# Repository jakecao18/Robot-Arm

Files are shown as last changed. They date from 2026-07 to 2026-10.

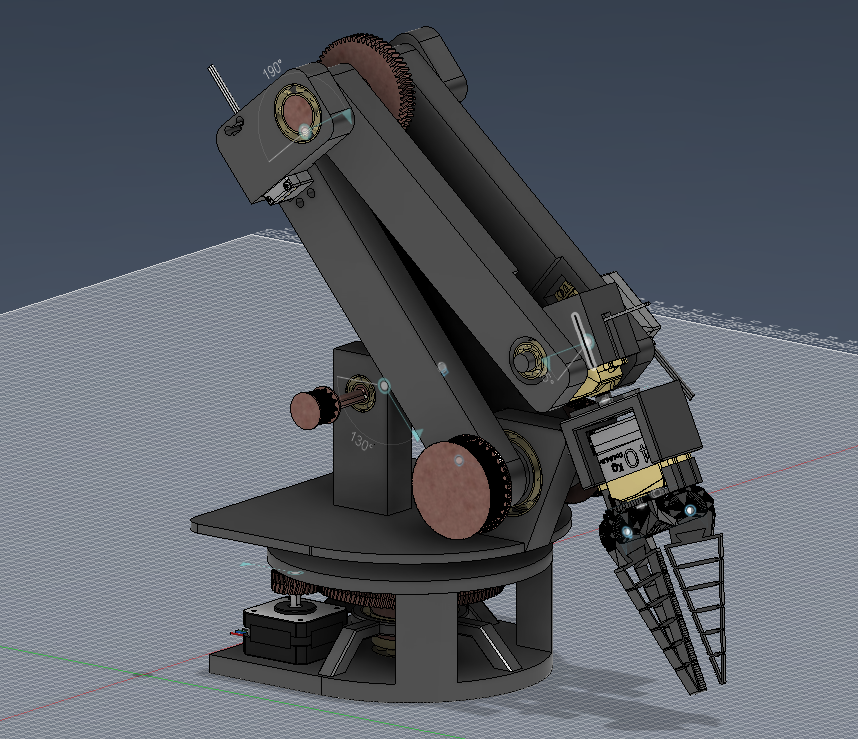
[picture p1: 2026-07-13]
Documents/pictures & videos/picture 5.png

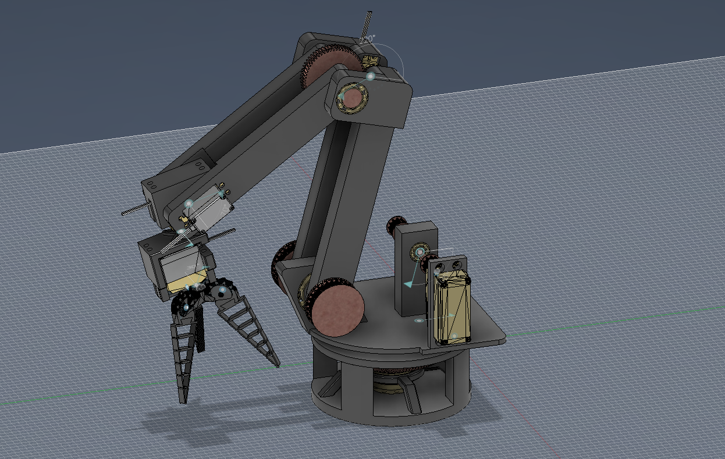
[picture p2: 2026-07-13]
Documents/pictures & videos/picture 1.png

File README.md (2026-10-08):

# 5-DOF Robotic Arm

A 5-DOF desktop robotic arm built for computer vision experiments and automated pick-and-place tasks.

The arm uses 3D-printed parts, high-torque hobby servos, and an ESP32 for control. Servo control is handled through a PCA9685 over I2C.

Part of the **Stardance** project.

## Hardware

| Component | Spec / Model | Qty | Notes |
| --- | --- | --: | --- |
| Microcontroller  | ESP32 DevKit V1 | 1 | Main controller |
| PWM Driver | PCA9685 16-Channel | 1 | I2C servo control |
| Base Servo | 150 kg·cm digital servo | 1 | Base rotation |
| Shoulder / Elbow | 40 kg·cm digital servos | 2 | Main arm joints |
| Wrist / Gripper  | 20 kg·cm digital servos | 2 | Wrist and gripper |
| Power Supply | 12V SMPS | 1 | Stepped down for the servo rail |

The full parts list, prices, and sourcing information are in [`Documents/BOM.csv`](Documents/BOM.csv).

## Project Status

* [x] Full CAD assembly in Fusion 360
* [x] Wiring schematic and power distribution
* [x] Bill of Materials
* [x] Structural parts 3D printed
* [x] Mechanical assembly and dry-fit
* [x] Servo calibration and zero-point alignment
* [x] Forward and inverse kinematics
* [x] ESP32 firmware and PCA9685 control
* [ ] OpenCV camera integration
* [ ] Object detection
* [ ] Autonomous pick-and-place

## Repository

```text
├── CAD/
│   ├── Assembly/              # Complete Fusion 360 models
│   └── Individual Parts/      # Printable STL/STEP files
│
├── Code/                      # ESP32 firmware and control scripts
│
├── Documents/
│   ├── BOM.csv                # Parts, pricing, and specifications
│   ├── Pictures/              # Build photos and progress
│   └── Wiring_Schematic.*     # System schematics
│
└── README.md
```

## Software

* **CAD:** Autodesk Fusion 360
* **Firmware:** C++ / Arduino IDE
* **Microcontroller:** ESP32
* **Servo Control:** PCA9685 over I2C
* **Kinematics:** Python, NumPy
* **Computer Vision:** OpenCV
* **Development:** VS Code

## License

MIT License

Designed and built by Jake.

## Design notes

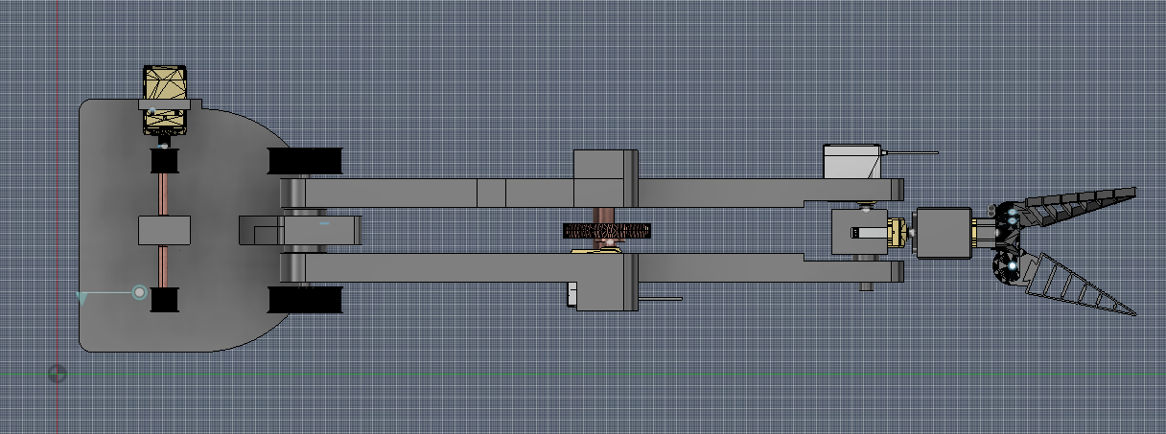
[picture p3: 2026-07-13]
Documents/pictures & videos/picture 4.png

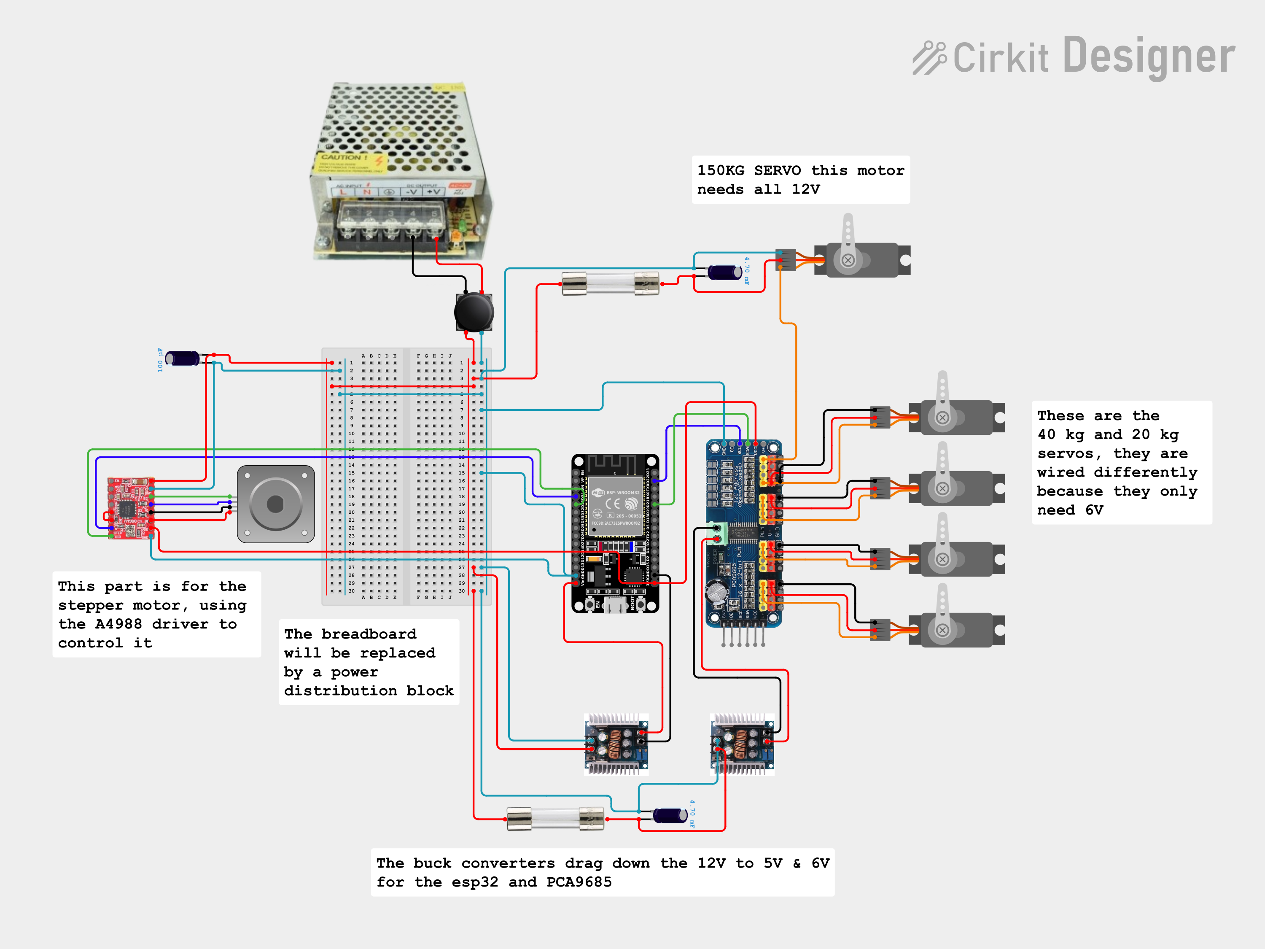
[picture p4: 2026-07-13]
Documents/pictures & videos/circuit_image.png

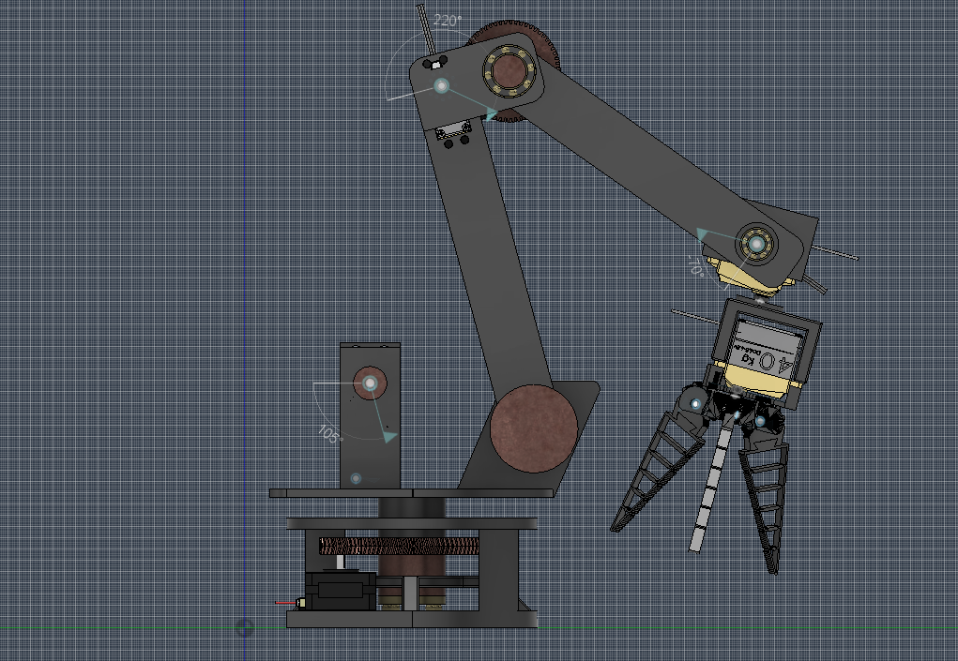
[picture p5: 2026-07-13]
Documents/pictures & videos/picture 2.png

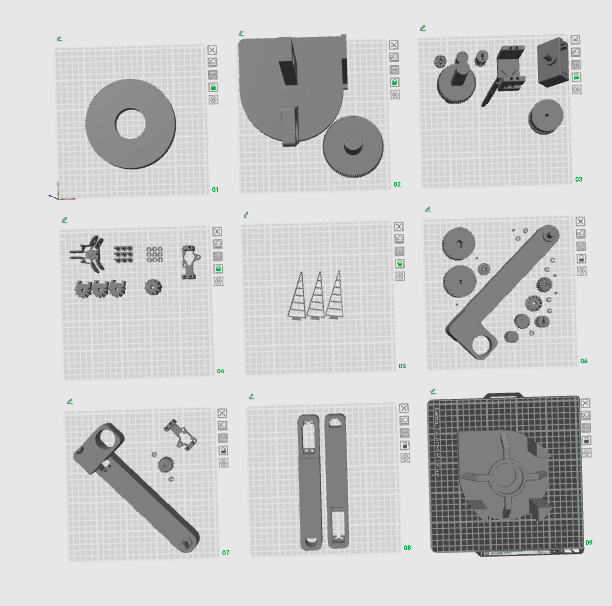
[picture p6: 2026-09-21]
Documents/pictures & videos/Screenshot 2026-07-12 210158.png

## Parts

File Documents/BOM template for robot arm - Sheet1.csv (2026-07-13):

Item Name | Qty | Price (total) (CAD) | Item link | Notes
nema 17 stepper | 1 | $15.99 | link | This is an example part! Add things to note here.
20kg servo | 2 | $35.99 | link | Servo for wrist roll and gripper
40kg servo | 2 | $45.59 | link | Servo for elbow and wrist
150kg servo | 1 | $46.99 | link | Servo for shoulder
esp32 | 1 | $8.06 | link | Microcontroller to control all motors
thrust ball bearing 20mm x 40mm x 14mm | 1 | $11.26 | link | Ball bearing at the base
ball bearing 10mm x 26mm x 8mm | 3 | $13.75 | link | Ball bearing at the shoulder and wrist
ball bearing 35mm x 47mm x 7mm | 2 | $12.89 | link | Ball bearing at the base
ball bearing 20mm x 32mm x 7mm | 2 | $11.09 | link | Ball bearing at the shoulder
HTD5M-325mm 15mm width pulley timing belt | 2 | $19.19 | link | Belt to connect belt gears on the shoulder
PCA9685 | 1 | $13.56 | link | Servo motor driver that handles outputting all the PWM signals
adjustable buck converter 12V - 5 & 6V | 2 | $19.99 | link | Buck convertor to lower voltage from 12V down to 5V for esp32 and 6V for PCA9685
capacitor 4700 uf | 2 | $11.32 | link | Capacitors will be used to prevent voltage spikes; this is for the servos. This is actually 5 pieces, although you just need 2
SMPS 12V 20A | 1 | $27.89 | link | Power cord not included, so you would need one. Cutting up an old computer power cord can also work
fuse | 2 | $11.69 | link | This is a 4-pack, but you only need 2. The fuses prevent short-circuit damage
power distribution block | 1 | $18.51 | link | Power distribution block lets everything be more organized, it's optional since wires can be plugged directly into the power supply
12 AWG wire | 3ft | $11.39 | link | Thicker wires can safely handle the 12V 20A power without any fluctuation or trouble, you would also need regular jumper wires
A4988 stepper motor driver | 1 | $3.50 | link | This part controls the stepper motor
capacitor 100 uf | 1 | $2.17 | link | This capacitor will be used for the stepper motor. This is 10 pieces but you only need 1
Total Price (USD): | $340.82
All of these parts are just the ones I found immediately on Amazon; you can probably find the exact same parts for cheaper on Amazon or even somewhere else.

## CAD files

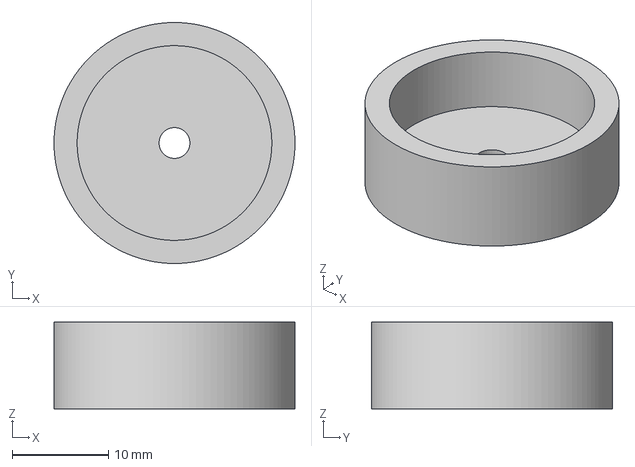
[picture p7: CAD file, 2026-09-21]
CAD files/CAD parts obj/elbow big gear cap.3mf
25.0 x 25.0 x 9.00 mm

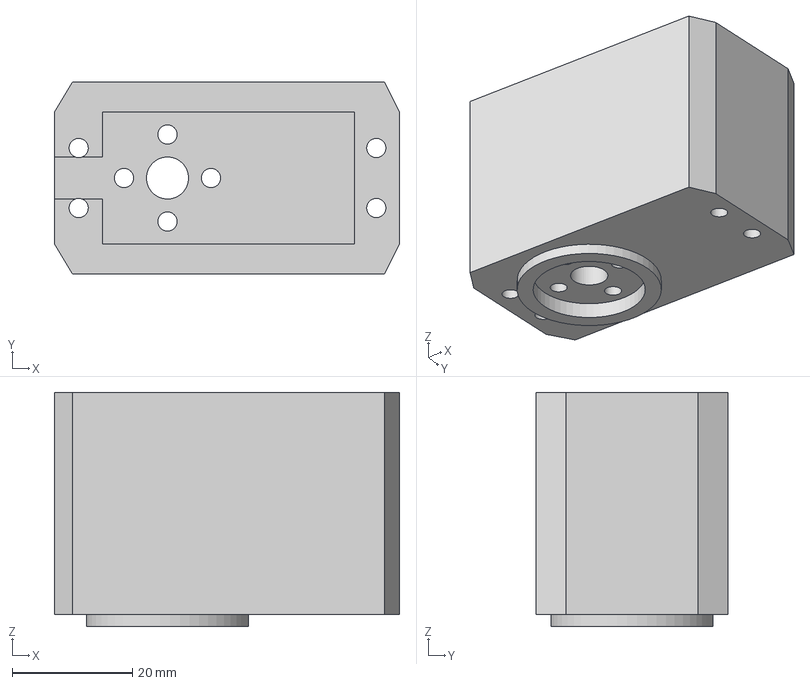
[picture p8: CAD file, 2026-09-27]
CAD files/CAD parts step/gripper holder.step
57.5 x 32.0 x 39.0 mm

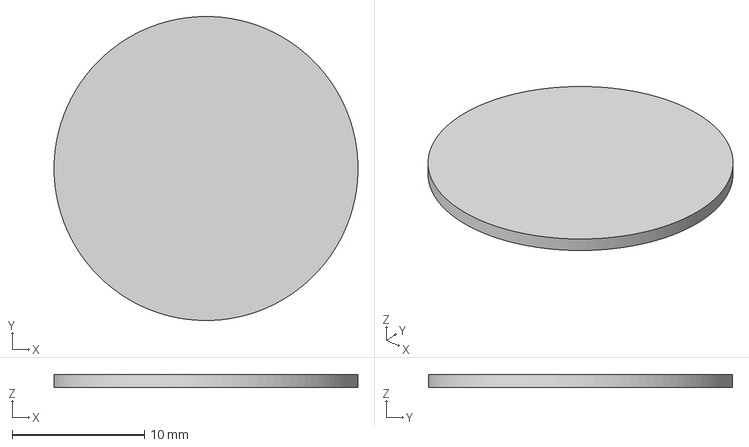
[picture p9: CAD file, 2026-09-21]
CAD files/CAD parts obj/elbow bb cover.3mf
23.0 x 23.0 x 1.00 mm

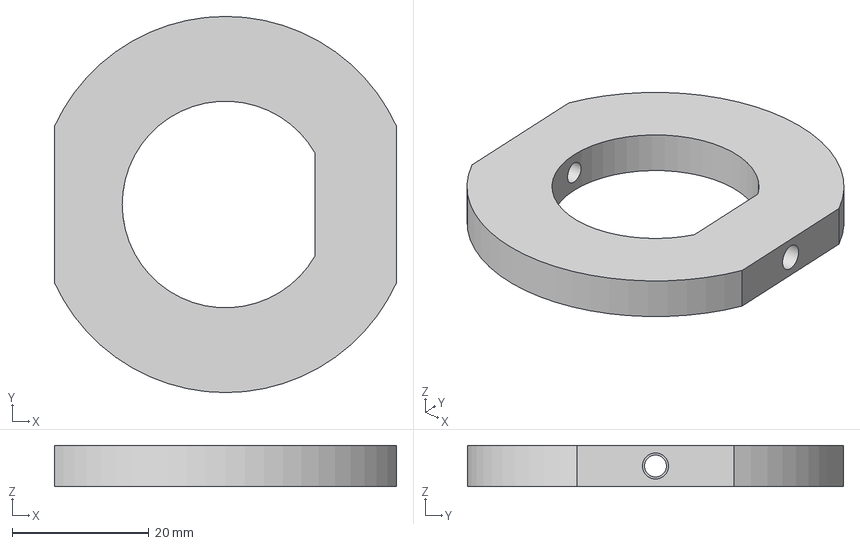
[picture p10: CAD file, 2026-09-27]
CAD files/CAD parts step/shoulder shaft connect support.step
50.0 x 55.0 x 6.00 mm

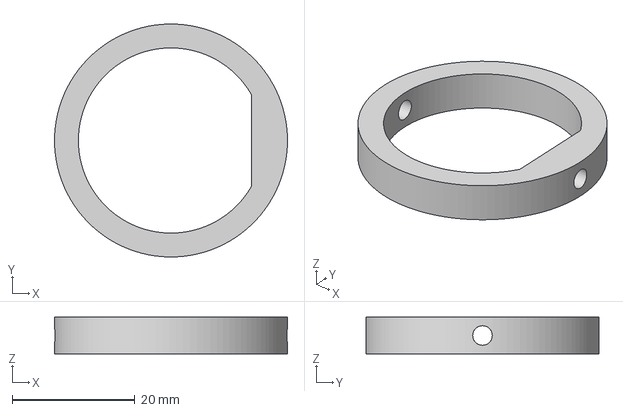
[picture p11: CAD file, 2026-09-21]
CAD files/CAD parts obj/shoulder shaft bearing holder.3mf
38.0 x 38.0 x 6.00 mm

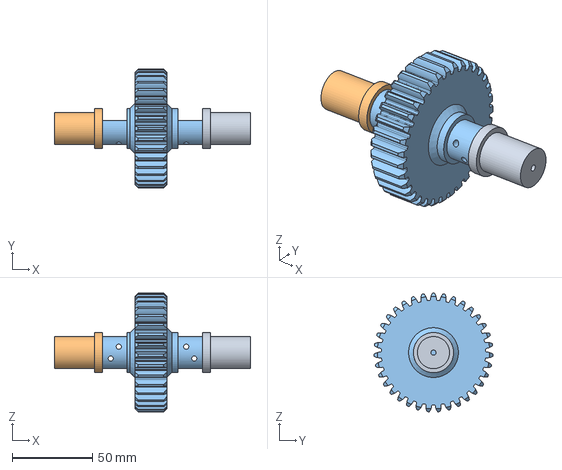
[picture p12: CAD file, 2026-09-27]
CAD files/CAD parts step/elbow big gear .step
122.0 x 74.0 x 73.9 mm

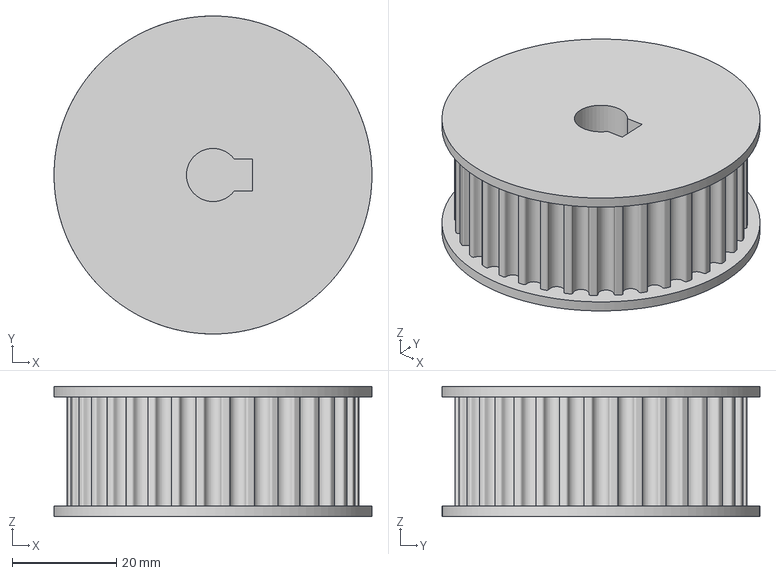
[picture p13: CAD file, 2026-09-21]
CAD files/CAD parts obj/shoulder big belt gear.3mf
61.0 x 61.0 x 25.0 mm

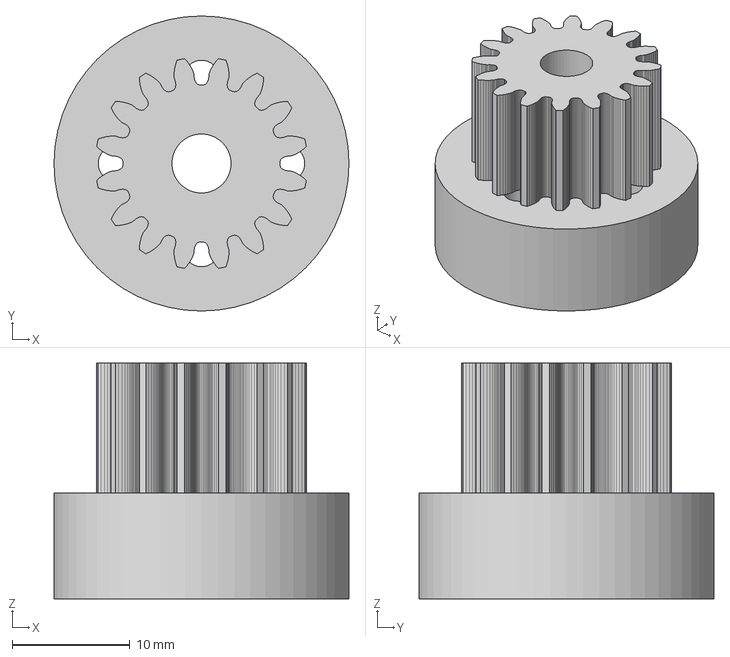
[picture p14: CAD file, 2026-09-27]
CAD files/CAD parts step/gripper pinion.step
25.0 x 25.0 x 20.0 mm

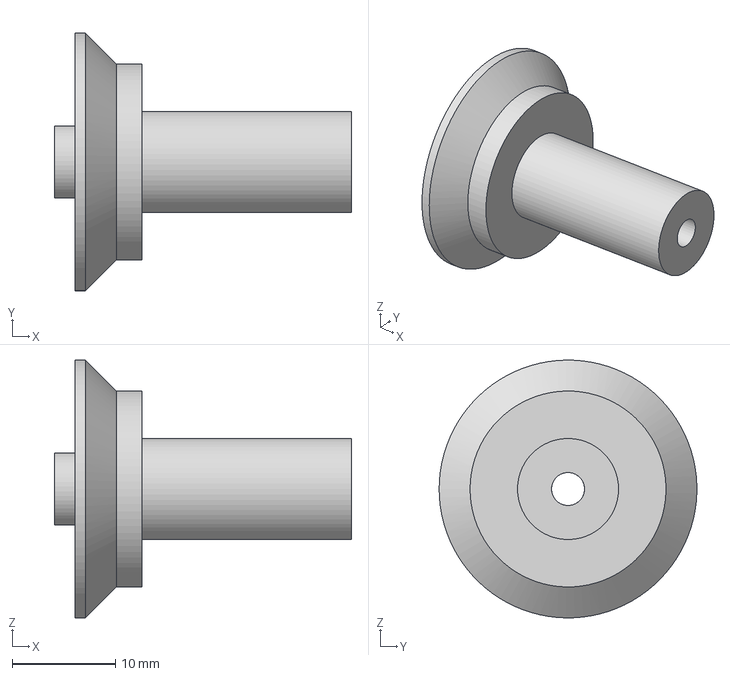
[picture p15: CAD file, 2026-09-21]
CAD files/CAD parts obj/wrist holder2.3mf
28.8 x 25.0 x 25.0 mm

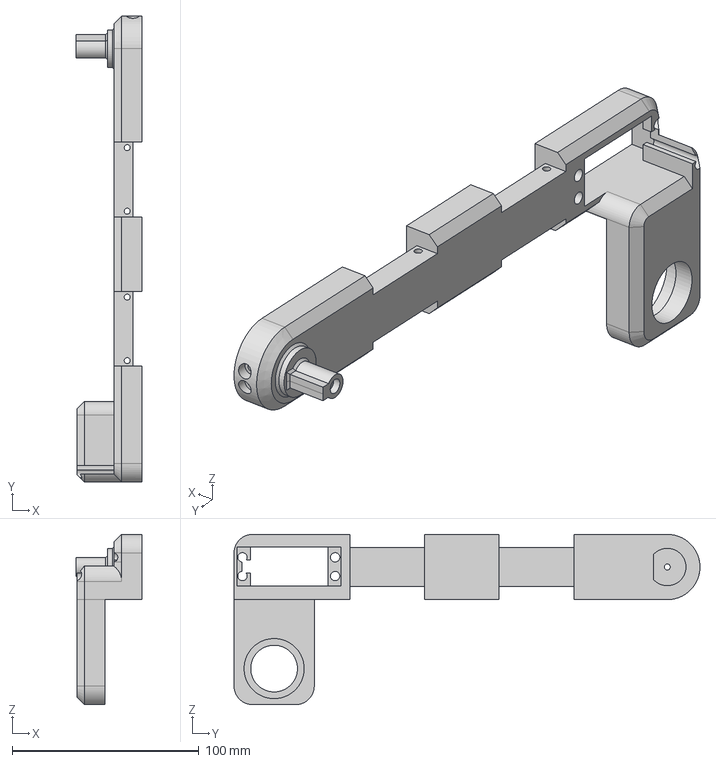
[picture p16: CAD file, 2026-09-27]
CAD files/CAD parts step/shoulder shaft right.step
35.5 x 249.5 x 91.2 mm

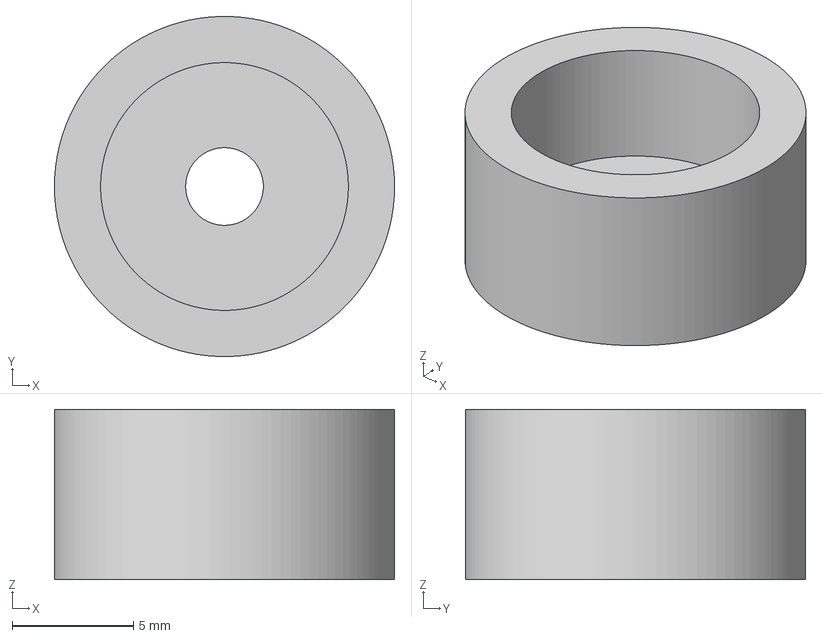
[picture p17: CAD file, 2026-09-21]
CAD files/CAD parts obj/elbow small gear cap.3mf
14.0 x 14.0 x 7.00 mm

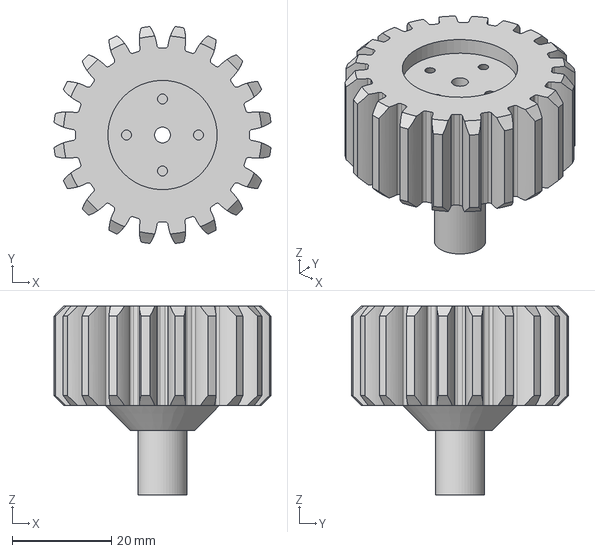
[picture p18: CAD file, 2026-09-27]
CAD files/CAD parts step/elbow small gear .step
43.7 x 43.7 x 38.0 mm

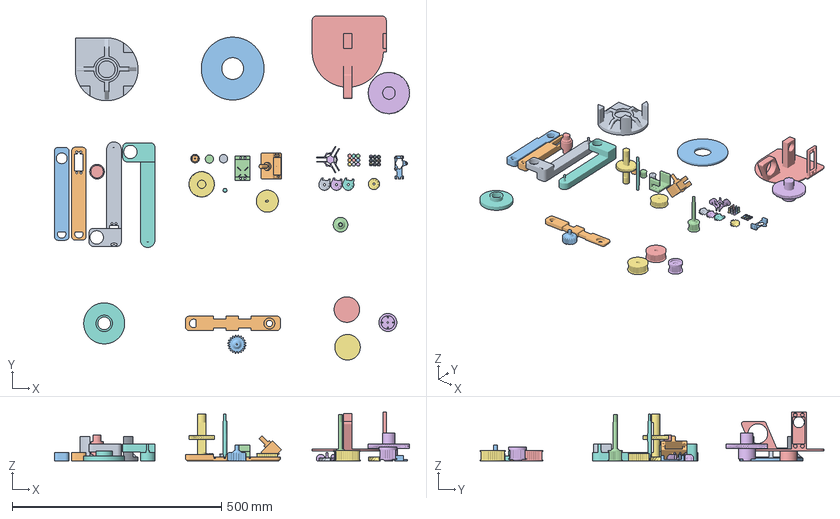
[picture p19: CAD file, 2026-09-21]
CAD files/CAD parts obj/base big gear.3mf
848.3 x 821.3 x 116.9 mm
base plate (1)
servo connect (1) (1)
top base plate
belt gear1 (1) x 2
shoulder plate (2) (2)
herringbone-97.obj
herringbone-59 (1)
arm shaft right (1) (1) (2)
arm shaft left (1) (1) (1) (1)
arm shaft left (3) (1) (2)
arm connect (1)
Gear_Holder
htd-pitch5mm-width15mm-32tooth
MeshBody7
base
Bolt_Clip x 9
Bolt x 9
Gear_1 (2) x 3
servo gear
MeshBody1 x 3
MeshBody1 (1) (1)

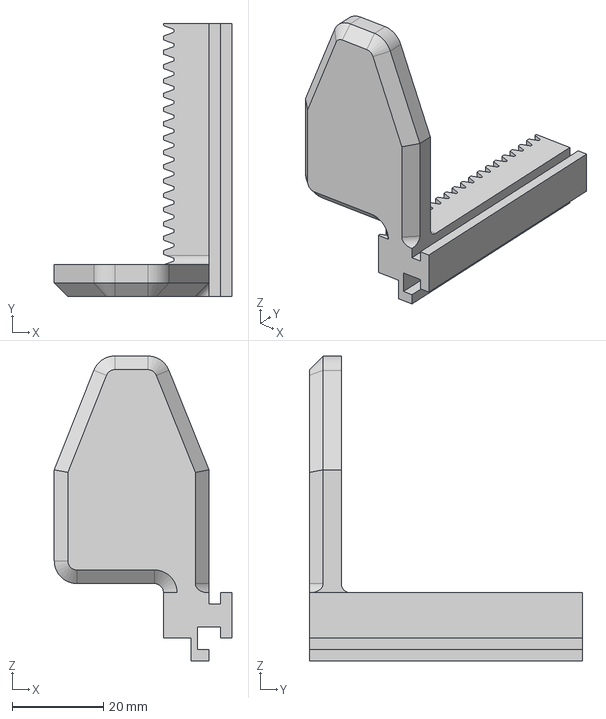
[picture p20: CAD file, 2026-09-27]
CAD files/CAD parts step/gripper rack.step
39.0 x 60.0 x 67.0 mm

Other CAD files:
CAD files/CAD parts obj/elbow big gear arms.3mf
CAD files/CAD parts step/shoulder shaft support.step
CAD files/CAD parts obj/gripper servo gear.3mf
CAD files/CAD parts step/top base plate.step
CAD files/CAD parts obj/base plate (1).3mf
CAD files/CAD parts obj/base small gear.3mf
CAD files/CAD parts obj/elbow big gear.3mf
CAD files/CAD parts obj/elbow shaft left.3mf
CAD files/CAD parts obj/elbow shaft right.3mf
CAD files/CAD parts obj/elbow shaft support.3mf
CAD files/CAD parts obj/elbow small gear.3mf
CAD files/CAD parts obj/gripper base.3mf
CAD files/CAD parts obj/gripper bolt clip.3mf
CAD files/CAD parts obj/gripper bolt.3mf
CAD files/CAD parts obj/gripper finger gear.3mf
CAD files/CAD parts obj/gripper finger.3mf
CAD files/CAD parts obj/gripper gear holder.3mf
CAD files/CAD parts obj/gripper holder.3mf
CAD files/CAD parts obj/servo attach plug.3mf
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

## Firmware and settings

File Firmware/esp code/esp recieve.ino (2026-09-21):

#include <Wire.h>
#include <Adafruit_PWMServoDriver.h>
#include <WiFiUdp.h>
#include <ArduinoJson.h>
#include <WiFi.h>

#define STEP_PIN 2
#define DIR_PIN 4
#define EN_PIN 23

long currentSteps = 0;
long targetSteps = 0;
long elbowCurrent = 90;
long wristPitchCurrent = 90;
long shoulderCurrent = 90;

unsigned long lastStepTime = 0;
const unsigned long stepInterval = 7000;  // microseconds

const char* ssid = "westlake2022";
const char* password = "workIsFUN2023";

WiFiUDP udp;

const int UDP_PORT = 5000;

Adafruit_PWMServoDriver pwm = Adafruit_PWMServoDriver();

//array of max and min of servos 0 - 4
//calibrated servos 0, 1, & 2 
int servoMax[] = {2930, 3000, 3000, 2750, 2750};
int servoMin[] = {480, 450, 450, 500, 500};

//function that converts angle into pwm pulse
void writeAngle(int servoNum, double angle){
  //servo-0 has a range of 270 degrees therefor needing seperate mapping
  if(servoNum == 0){
    angle = constrain(angle, 0, 270);
    double pwmSignal = map(angle, 0, 270, servoMin[servoNum], servoMax[servoNum]);
    pwm.writeMicroseconds(servoNum, pwmSignal);
  }
  else if(servoNum == 1 || servoNum == 2){
    angle = constrain(angle, 0, 298);
    double pwmSignal = map(angle, 0, 298, servoMin[servoNum], servoMax[servoNum]);
    pwm.writeMicroseconds(servoNum, pwmSignal);
  }
  else{
    angle = constrain(angle, 0, 270);
    double pwmSignal = map(angle, 0, 270, servoMin[servoNum], servoMax[servoNum]);
    pwm.writeMicroseconds(servoNum, pwmSignal);
    Serial.print(pwmSignal);
  }
}

void setStepperAngle(float angle) {
  // Convert angle to absolute step position
  targetSteps = round(angle / 1.8);
}

void runStepper() {
  // Already at target
  if (currentSteps == targetSteps) {
    return;
  }
  // Don't step too quickly
  if (micros() - lastStepTime < stepInterval) {
    return;
  }

  lastStepTime = micros();

  // Need to move forward
  if (targetSteps > currentSteps) {
    digitalWrite(DIR_PIN, HIGH);

    digitalWrite(STEP_PIN, HIGH);
    delayMicroseconds(2);
    digitalWrite(STEP_PIN, LOW);

    currentSteps++;
  }

  // Need to move backward
  else {
    digitalWrite(DIR_PIN, LOW);

    digitalWrite(STEP_PIN, HIGH);
    delayMicroseconds(2);
    digitalWrite(STEP_PIN, LOW);

    currentSteps--;
  }
}

void setup() {
  //initialize pwm
  pwm.begin();
  pwm.setPWMFreq(50);

  pinMode(23, OUTPUT);
  digitalWrite(23, LOW);

  WiFi.begin(ssid, password);
  Serial.begin(115200);

  while (WiFi.status() != WL_CONNECTED) {
      delay(500);
      Serial.print(".");
  }

  Serial.println();
  Serial.println("WiFi connected!");

  Serial.print("ESP32 IP address: ");
  Serial.println(WiFi.localIP());

  udp.begin(UDP_PORT);

  Serial.print("Listening on UDP port: ");
  Serial.println(UDP_PORT);

  pinMode(STEP_PIN, OUTPUT);
  pinMode(DIR_PIN, OUTPUT);
  pinMode(EN_PIN, OUTPUT);

  // Enable A4988
  digitalWrite(EN_PIN, LOW);
  digitalWrite(DIR_PIN, HIGH);

}

void moveShoulderSlow(int targetShoulder) {

  while (shoulderCurrent != targetShoulder) {

    if (shoulderCurrent < targetShoulder)
      shoulderCurrent++;
    else if (shoulderCurrent > targetShoulder)
      shoulderCurrent--;

    writeAngle(0, shoulderCurrent);

    delay(15);
  }
}


void moveElbowSlow(int targetElbow) {

  while (elbowCurrent != targetElbow) {

    if (elbowCurrent < targetElbow)
      elbowCurrent++;
    else if (elbowCurrent > targetElbow)
      elbowCurrent--;

    writeAngle(1, elbowCurrent);

    delay(15);
  }
}


void moveWristPitchSlow(int targetWristPitch) {

  while (wristPitchCurrent != targetWristPitch) {

    if (wristPitchCurrent < targetWristPitch)
      wristPitchCurrent++;
    else if (wristPitchCurrent > targetWristPitch)
      wristPitchCurrent--;

    writeAngle(2, wristPitchCurrent);

    delay(15);
  }
}

void loop() {

  int packetSize = udp.parsePacket();

  if (packetSize > 0) {

    char packet[256];

    int length = udp.read(packet, 255);
    packet[length] = '\0';

    Serial.print("Received: ");
    Serial.println(packet);

    JsonDocument data;

    DeserializationError error = deserializeJson(data, packet);

    if (error) {
      Serial.println("JSON error");
      return;
    }

    float base = data["base"];
    float shoulder = data["shoulder"];
    float elbow = data["elbow"];
    float wristPitch = data["wristPitch"];
    float wristRoll = data["wristRoll"];
    float gripper = data["gripper"];
    float esp_check = data["esp_check"];

    if (base == 0 && shoulder == 67.5 && elbow == 0 && wristPitch == 270 && esp_check == 1){
      moveShoulderSlow(shoulder);
      delay(1000);
      moveWristPitchSlow(wristPitch);
      delay(1000);
      moveElbowSlow(elbow);
      delay(1000);
      setStepperAngle(base);
      while(currentSteps != targetSteps){
        runStepper();
      }
      delay(1000);
    } else if (shoulder != 67.5 && esp_check == 1) {
      setStepperAngle(base);
      while(currentSteps != targetSteps){
        runStepper();
      }
      delay(1000);
      moveElbowSlow(elbow);
      moveWristPitchSlow(wristPitch);
      moveShoulderSlow(shoulder);
    }
    else if (esp_check == 0) {
      setStepperAngle(base);
      while(currentSteps != targetSteps){
        runStepper();
      }
      writeAngle(4, gripper);
      moveElbowSlow(elbow);
      moveWristPitchSlow(wristPitch);
      writeAngle(3, wristRoll);
      moveShoulderSlow(shoulder);
    }
  }
}

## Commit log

2026-07-13 adding all files
    [BOM template for robot arm - Sheet1.csv, base big gear.3mf, base plate (1).3mf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]
2026-09-21 Update documents and videos
    [base big gear.3mf, base small gear.3mf, elbow bb cover.3mf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]
2026-09-27 Update CAD & Firmware
    [Spur_Gear_40mm.STEP, Spur_Gear_60mm.STEP, base big gear.3mf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]
